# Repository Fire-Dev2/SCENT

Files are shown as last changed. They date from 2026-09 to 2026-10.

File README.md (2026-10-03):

# SCENT

Low-cost embedded electronic nose for volatile organic compound (VOC) headspace classification.

Data, acquisition code, and analysis code supporting:

> Nambi, T., Bhimireddy, N. & McElroy, J. P. *Isolating the contributions of
> resistance-ratio normalization and humidity fusion in a low-cost three-sensor
> offline electronic nose.* Manuscript sensors-4609768, under revision at *Sensors*.

---

## What this is

SCENT is an $83 open-hardware electronic nose. Three MQ-series metal oxide semiconductor (MOS) gas sensors sit in a 3D-printed PETG chamber with active purge fluidics. Acquisition, feature extraction, and classification all run on a Raspberry Pi 5 with no network dependency.

The chamber STL and the Fritzing wiring sketch are in [`hardware/`](hardware/).

Three results. Every figure below is the **mean ± SD across ten random seeds**,
each seed shared by the fold splitter and the forest, with the observed range in
brackets. Earlier versions of this README quoted a single seed's across-fold
spread, which is a different and smaller quantity.

| Feature set | Dataset | Accuracy |
|---|---|---|
| Three MQ channels | primary, n = 450 | **90.2 ± 0.5%** (89.3–90.9), chance 11.1% |
| Three MQ + BME680 relative humidity | primary, n = 450 | **99.3 ± 0.2%** (99.1–99.6) |
| Raw divider voltage | ablation, n = 245 | **86.2 ± 0.9%** (85.3–87.3) |
| Rs/R0 normalized | ablation, n = 245 | **82.4 ± 1.9%** (79.2–84.9) |

Humidity fusion is significant at every seed (McNemar p from 5.4×10⁻¹¹ to
6.8×10⁻⁹). Resistance-ratio normalization is not: across ten seeds McNemar p
ranges from 0.034 to 1.00, and only two of ten fall below 0.05. For the forest the 3.8-point drop
reaches trial-level significance at only two of ten seeds, but the same division
costs two linear classifiers 8-9 points, at eight and ten of ten seeds. The claim
is therefore **no benefit and a consistent cost**, not a neutral transform.

The residual glycerol/water confusion under the three MQ channels is physical, not a signal-conditioning artifact: both headspaces are water-dominated at ambient temperature. Resistance-ratio referencing does not resolve it; a humidity transducer does.

A leave-one-sensor-out ablation (`analysis/loso.py`) shows the array is not
minimal: differencing the full and reduced
models seed by seed, dropping **MQ-9** costs 0.89 ± 0.63 points on three channels,
with the two-channel model the more accurate at one of ten seeds, and −0.13 ± 0.16
points on four, where the reduced model is at least as accurate at every seed.
Dropping MQ-3 costs 8.58 ± 0.69 points and MQ-135 2.62 ± 0.63.

Repeated under the preparation-level holdout (train on batch A, test on the
held-out batch B), the direction is the same and somewhat stronger: dropping
MQ-9 costs −0.89 ± 2.61 points on three channels and −1.22 ± 1.92 on four, with
the reduced model at least as accurate at **8 of 10** seeds in both cases, while
dropping MQ-3 costs 10.89 ± 2.39 and 8.22 ± 2.17. The held-out preparation is 90
trials, so the intervals are wide; this constrains the direction of the MQ-9
result, not its magnitude.

---

## Repository contents

```
SCENT/
├── data/                  # 18 per-analyte CSVs = 450-trial primary acquisition;
│                        # New_Protocol_Dataset.csv = 245-trial ablation acquisition
│                        # (file-by-file breakdown under "Data" below)
├── hardware/              # chamber STL, Fritzing wiring sketch, part list
├── analysis/
│   ├── seed_sweep.py      # ten-seed sweep over the four feature sets
│   ├── loso.py            # leave-one-sensor-out and single-channel ablation
│   ├── learning_curve.py  # held-out accuracy against training-set size
│   └── tvoc_checks.py     # exclusion evidence for the CCS811 channel
├── results/               # JSON output of each script above, plus the per-seed CSV
├── acquisition.py         # runs one trial on the Raspberry Pi
├── scent_analysis.py      # single-seed results and Figures 3–6
├── Requirements.txt
├── LICENSE                # MIT — code
├── LICENSE-DATA           # CC BY 4.0 — data
└── README.md
```

`figures/` is generated output and is not committed.

---

## Acquisition

`acquisition.py` runs one trial of the three-phase protocol on the Pi:

| Phase | Duration | |
|---|---|---|
| baseline | 30 s | clean-air stabilization before the sample is introduced |
| exposure | 60 s | sample headspace present |
| purge | 120 s | active exhaust, sensors returning to baseline |

```bash
python3 acquisition.py --trial 1 --scent ethanol --outdir data
```

All channels are sampled at **1 Hz** and each phase is reduced to the **arithmetic mean** of its samples, so one trial yields one value per channel per phase and the script writes one record per trial.

**The analyses in the manuscript use the exposure-phase columns.** The deposited datasets below carry those columns only, under the shorter names given in the column table.

Two implementation details the manuscript relies on:

- The CCS811 environmental compensation register (`ENV_DATA`, `0x05`) is never written, so the TVOC and eCO2 outputs are independent of the BME680 readings.
- `wait_ccs_ready()` polls the data-ready flag before every read, so logged values are never stale returns from a failed transaction.

Hardware: MQ-3, MQ-9, and MQ-135 read through an ADS1115 on A0/A1/A2; BME680 for temperature and relative humidity; CCS811 for eCO2 and TVOC. All on I²C.

---

## Reproducing the reported values

```bash
git clone https://github.com/Fire-Dev2/SCENT.git
cd SCENT
pip install -r Requirements.txt

python3 scent_analysis.py --data-dir data --out-dir figures   # single-seed results, Figures 3-6
python3 analysis/seed_sweep.py                                 # the reported mean +/- SD
python3 analysis/loso.py                                       # leave-one-sensor-out
python3 analysis/learning_curve.py                             # accuracy vs training-set size
python3 analysis/tvoc_checks.py                                # CCS811 exclusion evidence
```

The four scripts in `analysis/` default to `--data-dir data --out-dir results`
and need no arguments from the repository root.

`scent_analysis.py` takes a few minutes, dominated by the label-permutation
test; pass `--permutations 60` to shorten it. `seed_sweep.py` and `loso.py`
fit ten seeds each and take a few minutes more.

**On seeds.** `scent_analysis.py` is deterministic at `random_state=42`, but a
single seed is a reproducibility guarantee, not an uncertainty estimate. Seed 42
sits at the top of the ten-seed range for humidity fusion and at the bottom for
the normalized ablation, so it flatters one result and penalises the other. The
intervals quoted in this README and in the manuscript come from
`analysis/seed_sweep.py`, which is the number to compare against.

**Outputs written to `figures/`:**

| Output | Corresponds to |
|---|---|
| `Figure2_confusion_matrix.png` / `.pdf` | Manuscript Fig. 3 |
| `Figure3_humidity_fusion.png` / `.pdf` | Manuscript Fig. 6 |
| `FigureS1_feature_importance.png` | Manuscript Fig. 4 |
| `FigureS2_normalization_ablation.png` | Manuscript Fig. 5 |
| `TableI_normalization.csv` | Manuscript Table 3 |
| `TableII_per_class_primary.csv` | Manuscript Table 1 |
| `TableS1_classifiers.csv` | Manuscript Table 2 |
| `TableS2_ablation_per_class.csv` | Per-class ablation detail |
| `TableS3_humidity_fusion.csv` | Manuscript Table 4 |
| `results_summary.json` | Every single-seed statistic, machine-readable |

**Outputs written to `results/` by the scripts in `analysis/`:**

| Output | Corresponds to |
|---|---|
| `seed_sweep_results.json`, `seed_sweep_per_seed.csv` | Manuscript Table 8, the reported intervals |
| `loso_results.json` | Leave-one-sensor-out and its preparation-level repeat, Section 3.3, Tables S5/S5b/S5c |
| `learning_curve_results.json` | Manuscript Fig. 9 |
| `tvoc_checks_results.json` | Supplementary Tables S1–S4 |

The script also prints the exact binomial and permutation tests against chance, the McNemar and paired-t tests on the normalization ablation, the batch and cross-day holdouts, the seven-classifier comparison, and the per-analyte mean humidity that underpins the physical explanation.

**Versions used for the reported numbers:** Python 3.12.3, scikit-learn 1.8.0, statsmodels, scipy, numpy, pandas, matplotlib. Minor scikit-learn version differences may shift accuracy in the third decimal place.

---

## Data

### Primary dataset — 450 trials

In `data/`. Nine analytes, 50 trials each, acquired in two batches per analyte (40 and 10 trials) **on separate days**. Trial order was randomized and interleaved across analytes rather than blocked, so within-session baseline drift is distributed across classes rather than confounded with class identity.

| Analyte | Batch A (40 trials) | Batch B (10 trials) |
|---|---|---|
| Acetone | `MQ-3_Sensor_Data_Acetone_80.csv` | `MQ-3_Sensor_Data_Acetone_20.csv` |
| Acetic acid | `Acetic_Acid_80_Data.csv` | `Acetic_Acid_20_Data.csv` |
| Ammonia | `MQ-3_Sensor_Data_Ammonia_80.csv` | `MQ-3_Sensor_Data_Ammonia_20.csv` |
| Distilled water | `MQ-3_Sensor_Data_Distilled_Water_80.csv` | `MQ-3_Sensor_Data_Distilled_Water_20.csv` |
| Ethanol | `Ethanol_80_Sensor_Data.csv` | `Ethanol_20_Sensor_Data.csv` |
| Ethyl acetate | `Ethyl_Acetate_80_Sensor_Data.csv` | `Ethyl_Acetate_20.csv` |
| Glycerol | `Glycerol_80_Data.csv` | `Glycerol_20_Sensor_Data.csv` |
| Hydrogen peroxide | `Hydrogen_Peroxide_80_Sensor_Data.csv` | `Hydrogen_Peroxide_20.csv` |
| Propylene glycol | `Propylene_Glycol_80_Data.csv` | `Propylene_Glycol_20_Sensor_Data.csv` |

The `_80` / `_20` suffixes refer to the trial split, not to concentration. All analytes were used undiluted as purchased, 5 mL per trial, equilibrated 30 min before sampling.

### Ablation dataset — 245 trials

In `data/New_Protocol_Dataset.csv`. Same nine analytes under a modified protocol in which the **clean-air baseline resistance R₀ of each channel was recorded immediately before every exposure**, permitting resistance-ratio features to be computed per trial. Acquired over two days (`Batch_Day` column): 35 trials each for glycerol and distilled water, the pair responsible for the dominant error mode, and 25 for each of the other seven.

This is a separate acquisition from the primary dataset, so the headline three-channel accuracy and the raw-versus-normalized comparison are **not matched trial-for-trial** — stated as a limitation in the manuscript.

### Column format

| Column | Units | Description |
|---|---|---|
| `MQ3_V` | V | MQ-3 divider output (alcohol-sensitive) |
| `MQ9_V` | V | MQ-9 divider output (combustible aliphatics, CO) |
| `MQ135_V` | V | MQ-135 divider output (air quality, NH₃) |
| `MQ3_R0`, `MQ9_R0`, `MQ135_R0` | load-resistor units | Per-trial clean-air baseline resistance (ablation dataset only) |
| `TVOC_ppb` | ppb | Total VOC, CCS811 — **excluded from all analyses, see below** |
| `eCO2_ppm` | ppm | Equivalent CO₂, CCS811 |
| `Temp_C` | °C | In-chamber temperature, BME680 |
| `Humidity_pct` | % RH | In-chamber relative humidity, BME680 |
| `Trial_ID` | — | Trial index within analyte |
| `Batch_Day` | — | Acquisition day (ablation dataset only) |
| `Label` | — | Analyte name |

Every value is the mean over the 60 s exposure phase, 60 samples per trial.

**Classifier inputs:** the three MQ voltages for the primary result; those three plus `Humidity_pct` for the fusion result; Rs/R0 derived from the MQ voltages and the R₀ columns for the ablation. `eCO2_ppm` and `Temp_C` are evaluated as alternative fourth features but are not part of the headline model.

### The TVOC column

`TVOC_ppb` is **excluded from every analysis** and is retained only for completeness. Across both datasets the nine analyte classes occupy strictly disjoint TVOC bands, with a minimum inter-class gap of +4.635 pooled standard deviations and no overlap in any of the 36 class pairs; every other channel has a negative minimum gap and overlapping pairs. Fitted alone the channel classifies all nine analytes at 100.0 ± 0.0%.

Acquisition-order artifacts, derivation from the MOS channels, environmental compensation, cached reads, and quantization have been excluded. The behavior is unexplained and is reported as such in the manuscript. Do not use this column.

### Feature definitions

Raw features are the divider voltages as logged. Resistance-ratio features are computed as

```
Rs/RL = (Vc / Vout) − 1        with Vc = 5 V
feature = (Rs/RL) / R0         per channel, per trial
```

R₀ is logged in load-resistor units, so RL cancels in the ratio.

### Data integrity

The analysis script runs automatic checks before computing any metric: trial counts, class balance, exact-duplicate detection, and per-analyte signal spread. The spread check exists because a batch of genuinely independent trials varies well above ADC quantisation; a near-zero spread indicates replicated or derived rows rather than independent measurements. Both datasets pass, and the check prints a warning naming any analyte that fails.

---

## Licensing

- **Code**: MIT — see `LICENSE`
- **Data**: CC BY 4.0 — see `LICENSE-DATA`

Both permit reuse with attribution.

---

## Citation

Please cite the manuscript. The repository is referenced in the paper as:

```
https://github.com/Fire-Dev2/SCENT
```

Tagged releases are listed under Releases.

---

## Contact

Tharun Nambi — tharun.nambi@osumc.edu — ORCID [0009-0001-1177-6635](https://orcid.org/0009-0001-1177-6635)

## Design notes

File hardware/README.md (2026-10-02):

# Hardware

Design files for the SCENT chamber and sensor wiring.

| File | What it is |
|---|---|
| `SCENT_chamber.stl` | Sensor chamber, binary STL, 21,512 triangles |
| `SCENT_wiring.fzz` | Fritzing sketch — the full wiring, editable source |
| `SCENT_wiring_breadboard.png` | Breadboard view exported from that sketch |

## Chamber

Printed in PETG. The mesh bounding box is **161.0 × 101.6 × 200.0** model
units; STL stores no unit, and the model was authored in millimetres.

Open `SCENT_chamber.stl` in any slicer. No supports were used for the
reported build.

## Wiring

`SCENT_wiring.fzz` opens in [Fritzing](https://fritzing.org). The Fritzing
library names the ADS1115, BME680 and CCS811 parts after Adafruit because those
are the symbols it ships; the units actually built with were generic
equivalents, as `BOM.csv` records:

| Part | Role |
|---|---|
| Raspberry Pi 5 | acquisition host, I²C master |
| ADS1115 | 16-bit I²C ADC, reads the three MOS dividers on A0/A1/A2 |
| MQ-3 breakout | alcohols |
| MQ-9 breakout | combustible aliphatics, CO |
| Gas sensor breakout (MQ-135) | air quality, NH₃ |
| BME680 breakout | in-chamber temperature and relative humidity |
| CCS811 breakout | eCO2 and TVOC — logged, excluded from every analysis |
| 2-pin fan | active purge exhaust |
| Momentary push button | trial start |

Wire colours in the breadboard view:

| Colour | Carries |
|---|---|
| Red | 5.5 V supply |
| Purple | 3.3 V supply |
| Blue | ground |
| Orange | analogue output from the MOS breakouts to the ADS1115 |
| Green | I²C address lines |
| Grey | I²C serial data |
| Brown | slow control adapter lines |

The MOS breakouts run at 5 V and reach the Pi only through the ADS1115, so
no 5 V line touches a Pi GPIO pin. The BME680 and CCS811 are 3.3 V I²C
devices on the Pi's own bus.

## Bill of materials

`BOM.csv` — thirteen line items totalling **USD 83.00**, which is the figure
quoted in the manuscript.

| Category | USD |
|---|---|
| Compute (Pi 5 1 GB, PSU, microSD) | 53.00 |
| Sensors (3 × MQ, BME680, CCS811) | 15.80 |
| Electronics (ADS1115, fan, button, breadboard and wire) | 5.95 |
| Chamber (PETG, 750 g at $11/kg) | 8.25 |
| **Total** | **83.00** |

Read it with these caveats:

- **Component cost only.** No shipping, tax, soldering iron, printer or
  laptop. The build assumes you already have a 3D printer.
- **Sourcing.** Everything but the Raspberry Pi came from AliExpress. The
  sensor breakouts are generic rather than Adafruit or SparkFun parts, which
  is most of why the sensing array comes to $15.80; the equivalent
  Adafruit units would roughly treble that line.
- **Not calibrated parts.** Generic MOS breakouts carry no calibration
  certificate and unit-to-unit variation is not characterised here. The
  classification results are for the specific units built, which is already
  a stated limitation.
- **Prices move.** The Pi 5 1 GB exists at $45 because memory prices rose;
  the same pressure moves the other lines. The total is the cost at the time of purchase.
- **Filament is the softest line.** 750 g at $0.011/g is the amount of PETG
  attributed to one chamber. If that is a spool purchased rather than the
  mass the slicer reports for this print, the per-device figure is lower and
  the total falls below 83.

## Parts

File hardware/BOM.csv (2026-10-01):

Part | Qty | Supplier | Unit USD | Line USD | Role
Raspberry Pi 5, 1 GB | 1 | PiShop / approved reseller | 45.00 | 45.00 | compute module
Power supply, 5 V 3 A USB-C (generic) | 1 | AliExpress | 4.00 | 4.00
microSD card, 32 GB | 1 | AliExpress | 4.00 | 4.00
ADS1115 16-bit I2C ADC | 1 | AliExpress | 2.00 | 2.00 | reads the three MOS dividers
MQ-3 breakout | 1 | AliExpress | 1.30 | 1.30 | alcohols
MQ-9 breakout | 1 | AliExpress | 1.50 | 1.50 | combustible aliphatics, CO
MQ-135 breakout | 1 | AliExpress | 1.50 | 1.50 | air quality, NH3
BME680 breakout (generic) | 1 | AliExpress | 6.50 | 6.50 | temperature, relative humidity
CCS811 breakout (generic) | 1 | AliExpress | 5.00 | 5.00 | eCO2, TVOC; logged, excluded from analysis
Fan, 2-pin | 1 | AliExpress | 1.20 | 1.20 | active purge exhaust
Momentary push button | 1 | AliExpress | 0.25 | 0.25 | trial start
Breadboard and jumper wires | 1 | AliExpress | 2.50 | 2.50
PETG filament, 750 g | 1 | AliExpress, $11/kg | 8.25 | 8.25 | chamber print; $0.011/g
TOTAL |  |  |  | 83.00

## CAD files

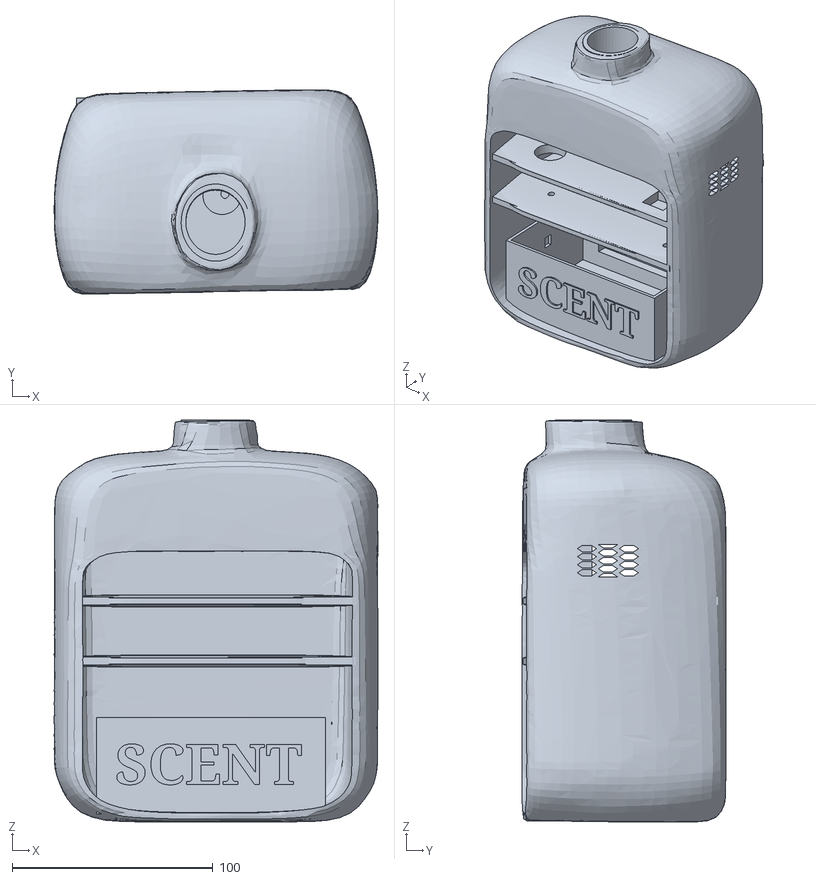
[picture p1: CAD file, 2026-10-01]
hardware/SCENT_chamber.stl
161.0 x 101.6 x 200.0

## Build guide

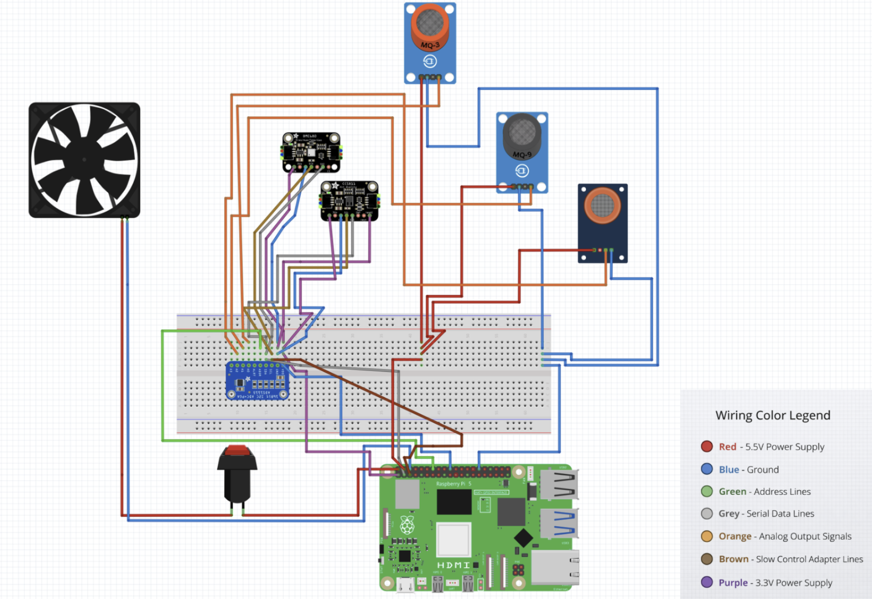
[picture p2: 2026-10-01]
hardware/SCENT_wiring_breadboard.png

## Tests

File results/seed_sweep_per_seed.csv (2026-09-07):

seed | feature_set | accuracy_pct | mcnemar_p_humidity_fusion_B_vs_A | mcnemar_p_normalization_D_vs_C
0 | A. Primary 3-MOS (n=450) | 90.6667
0 | B. Primary 3-MOS + humidity (n=450) | 99.1111 | 1.94671e-09
0 | C. Ablation raw voltage (n=245) | 87.3469
0 | D. Ablation Rs/R0 (n=245) | 84.4898 |  | 0.360196
1 | A. Primary 3-MOS (n=450) | 89.3333
1 | B. Primary 3-MOS + humidity (n=450) | 99.3333 | 5.41216e-11
1 | C. Ablation raw voltage (n=245) | 86.9388
1 | D. Ablation Rs/R0 (n=245) | 83.2653 |  | 0.243243
2 | A. Primary 3-MOS (n=450) | 90.4444
2 | B. Primary 3-MOS + humidity (n=450) | 99.5556 | 1.06106e-09
2 | C. Ablation raw voltage (n=245) | 85.3061
2 | D. Ablation Rs/R0 (n=245) | 81.6327 |  | 0.243243
3 | A. Primary 3-MOS (n=450) | 90.2222
3 | B. Primary 3-MOS + humidity (n=450) | 99.5556 | 2.50886e-10
3 | C. Ablation raw voltage (n=245) | 85.3061
3 | D. Ablation Rs/R0 (n=245) | 84.8980 |  | 1
4 | A. Primary 3-MOS (n=450) | 90.2222
4 | B. Primary 3-MOS + humidity (n=450) | 99.3333 | 4.18544e-10
4 | C. Ablation raw voltage (n=245) | 87.3469
4 | D. Ablation Rs/R0 (n=245) | 81.6327 |  | 0.0714235
5 | A. Primary 3-MOS (n=450) | 89.5556
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

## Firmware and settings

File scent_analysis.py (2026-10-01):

#!/usr/bin/env python3
"""
SCENT: nine-class chemical headspace classification from a low-cost MOS sensor array.

Reproduces the single-seed results and Figures 2-5.

The seed sweep, leave-one-sensor-out ablation, learning curve and CCS811
exclusion checks live in analysis/ and are run separately. The intervals
quoted in the manuscript come from analysis/seed_sweep.py, not from the
across-fold spread this script prints.

  Primary dataset (450 trials, 9 analytes, 3 MQ channels)
    five-fold stratified CV accuracy and macro F1; exact binomial and
    label-permutation tests against chance; per-class precision/recall (Table II);
    pooled out-of-fold confusion matrix (Fig. 2); Gini channel importances (Fig. S1);
    batch holdout across acquisition days; seven-classifier comparison (Table S1).

  Ablation dataset (245 trials, per-trial clean-air R0 recorded)
    raw divider voltage vs Rs/R0 features (Table I); McNemar and paired t tests;
    per-class F1 under both representations (Table S2); confusion matrices (Fig. S2).

  Humidity fusion (both datasets)
    BME680 relative humidity as a fourth feature (Fig. 3, Table S3);
    McNemar against the three-channel model.

Usage:
    python scent_analysis.py --data-dir data --out-dir figures
    python scent_analysis.py --data-dir data --out-dir figures --permutations 200

Deterministic at random_state=42, which is a reproducibility guarantee and
not an uncertainty estimate; see analysis/seed_sweep.py. Runtime is a few minutes, dominated by the
permutation test; lower --permutations to shorten it.
"""

import argparse, json, sys
from pathlib import Path

import numpy as np
import pandas as pd
from sklearn.ensemble import RandomForestClassifier
from sklearn.linear_model import LogisticRegression
from sklearn.metrics import accuracy_score, classification_report, confusion_matrix
from sklearn.model_selection import (StratifiedKFold, cross_val_predict,
                                     cross_val_score, permutation_test_score)
from sklearn.naive_bayes import GaussianNB
from sklearn.neighbors import KNeighborsClassifier
from sklearn.pipeline import make_pipeline
from sklearn.preprocessing import StandardScaler
from sklearn.svm import SVC
from sklearn.tree import DecisionTreeClassifier

RANDOM_STATE = 42
N_ESTIMATORS = 100
N_SPLITS = 5
VC = 5.0

MQ = ["MQ3_V", "MQ9_V", "MQ135_V"]
R0 = ["MQ3_R0", "MQ9_R0", "MQ135_R0"]
RH = "Humidity_pct"

PRIMARY = {
    "Acetone":           ("MQ-3_Sensor_Data_Acetone_80.csv", "MQ-3_Sensor_Data_Acetone_20.csv"),
    "Acetic_Acid":       ("Acetic_Acid_80_Data.csv", "Acetic_Acid_20_Data.csv"),
    "Ammonia":           ("MQ-3_Sensor_Data_Ammonia_80.csv", "MQ-3_Sensor_Data_Ammonia_20.csv"),
    "Distilled_Water":   ("MQ-3_Sensor_Data_Distilled_Water_80.csv", "MQ-3_Sensor_Data_Distilled_Water_20.csv"),
    "Ethanol":           ("Ethanol_80_Sensor_Data.csv", "Ethanol_20_Sensor_Data.csv"),
    "Ethyl_Acetate":     ("Ethyl_Acetate_80_Sensor_Data.csv", "Ethyl_Acetate_20.csv"),
    "Glycerol":          ("Glycerol_80_Data.csv", "Glycerol_20_Sensor_Data.csv"),
    "Hydrogen_Peroxide": ("Hydrogen_Peroxide_80_Sensor_Data.csv", "Hydrogen_Peroxide_20.csv"),
    "Propylene_Glycol":  ("Propylene_Glycol_80_Data.csv", "Propylene_Glycol_20_Sensor_Data.csv"),
}
ABLATION = "New_Protocol_Dataset.csv"

DISPLAY = {"Acetic_Acid":"Acetic acid","Acetone":"Acetone","Ammonia":"Ammonia",
 "Distilled_Water":"Distilled water","Ethanol":"Ethanol","Ethyl_Acetate":"Ethyl acetate",
 "Glycerol":"Glycerol","Hydrogen_Peroxide":"Hydrogen peroxide","Propylene_Glycol":"Propylene glycol"}
CHANNEL = {"MQ3_V":"MQ-3 (alcohol)","MQ9_V":"MQ-9 (combustible aliphatics, CO)",
 "MQ135_V":"MQ-135 (air quality / NH3)", RH:"BME680 (relative humidity)"}


def rf():
    return RandomForestClassifier(n_estimators=N_ESTIMATORS, random_state=RANDOM_STATE)

def folds():
    return StratifiedKFold(n_splits=N_SPLITS, shuffle=True, random_state=RANDOM_STATE)


def load_primary(data_dir):
    frames, missing = [], []
    for analyte, (fa, fb) in PRIMARY.items():
        for fname, batch in ((fa, "A"), (fb, "B")):
            p = data_dir / fname
            if not p.exists():
                missing.append(fname); continue
            d = pd.read_csv(p); d["Analyte"] = analyte; d["Batch"] = batch
            frames.append(d)
    if missing:
        sys.exit(f"Missing {len(missing)} primary file(s) in {data_dir}:\n  " + "\n  ".join(missing))
    return pd.concat(frames, ignore_index=True)


def load_ablation(data_dir):
    p = data_dir / ABLATION
    if not p.exists():
        sys.exit(f"Missing ablation dataset: {p}")
    d = pd.read_csv(p)
    d["Analyte"] = d["Label"].str.replace(" ", "_")
    return d


def rs_over_r0(df):
    """Rs/RL = (Vc/Vout - 1), divided by the per-trial R0 of the same channel.
    R0 is logged in load-resistor units, so RL cancels."""
    rs = np.column_stack([(VC / df[c].values - 1) for c in MQ])
    return rs / df[R0].values


def integrity(df, name, feats):
    counts = df["Analyte"].value_counts()
    n_dup = int(df.duplicated(subset=feats).sum())
    print(f"=== {name}: integrity ===")
    print(f"  trials {len(df)}, classes {counts.size}, per class {counts.min()}-{counts.max()}")
    print(f"  exact duplicate feature rows: {n_dup}")
    flagged = []
    for a in sorted(df["Analyte"].unique()):
        s = df[df["Analyte"] == a]
        spread = float(s["MQ3_V"].max() - s["MQ3_V"].min())
        if spread < 0.005:
            flagged.append((a, spread))
    if flagged:
        print("  LOW-VARIANCE WARNING (possible derived or replicated rows):")
        for a, s in flagged:
            print(f"    {a}: MQ3_V spread {s:.5f} V")
    else:
        print("  per-analyte MQ3_V spread: all above quantisation floor")
    print()
    return {"n": int(len(df)), "duplicates": n_dup,
            "low_variance_analytes": [a for a, _ in flagged]}


def analyse_primary(df, n_perm):
    from scipy.stats import binomtest
    X, y = df[MQ].values, df["Analyte"].values
    classes = sorted(set(y)); chance = 1.0 / len(classes); cv = folds()

    acc = cross_val_score(rf(), X, y, cv=cv, scoring="accuracy")
    f1  = cross_val_score(rf(), X, y, cv=cv, scoring="f1_macro")
    yp  = cross_val_predict(rf(), X, y, cv=cv)
    ncorr = int((yp == y).sum())

    print("=== Primary dataset, three MQ channels ===")
    print(f"  accuracy {acc.mean()*100:.1f} +/- {acc.std()*100:.1f}%   macro F1 {f1.mean():.3f} +/- {f1.std():.3f}")
    print(f"  folds {np.round(acc,4)}")
    print(f"  {ncorr}/{len(y)} correct; chance {chance*100:.1f}%")
    bp = binomtest(ncorr, len(y), chance, alternative="greater").pvalue
    print(f"  exact binomial p = {bp:.3e}")

    score, perm, pp = permutation_test_score(rf(), X, y, scoring="accuracy", cv=cv,
        n_permutations=n_perm, random_state=RANDOM_STATE, n_jobs=-1)
    print(f"  permutation ({n_perm}): permuted {perm.mean()*100:.1f} +/- {perm.std()*100:.1f}%, "
          f"max {perm.max()*100:.1f}%, p = {pp:.4f}")
    print(f"    (minimum attainable p = {1/(n_perm+1):.4f})")

    a, b = df[df.Batch=="A"], df[df.Batch=="B"]
    ho = accuracy_score(b["Analyte"], rf().fit(a[MQ], a["Analyte"]).predict(b[MQ]))
    print(f"  batch holdout (train day 1 -> test day 2): {ho*100:.1f}%")

    imp = dict(zip(MQ, rf().fit(X, y).feature_importances_.tolist()))
    print("  Gini importances: " + ", ".join(f"{k} {v:.3f}" for k, v in imp.items()))
    print(); print(classification_report(y, yp, digits=3))

    rep = classification_report(y, yp, output_dict=True, digits=3)
    return {"classes":classes,"chance":chance,
            "accuracy_mean":float(acc.mean()),"accuracy_std":float(acc.std()),
            "macro_f1_mean":float(f1.mean()),"macro_f1_std":float(f1.std()),
            "n_correct":ncorr,"n_total":int(len(y)),"binomial_p":float(bp),
            "permutation_p":float(pp),"permuted_mean":float(perm.mean()),
            "permuted_std":float(perm.std()),"permuted_max":float(perm.max()),
            "batch_holdout":float(ho),"importances":imp,
            "per_class":{c:rep[c] for c in classes},
            "confusion_matrix":confusion_matrix(y,yp,labels=classes).tolist()}


def compare_classifiers(df):
    X, y = df[MQ].values, df["Analyte"].values
    cv = folds()
    models = {
      "Support vector machine (RBF)": make_pipeline(StandardScaler(), SVC(kernel="rbf", random_state=RANDOM_STATE)),
      "Support vector machine (linear)": make_pipeline(StandardScaler(), SVC(kernel="linear", random_state=RANDOM_STATE)),
      "Gaussian naive Bayes": make_pipeline(StandardScaler(), GaussianNB()),
      "Logistic regression": make_pipeline(StandardScaler(), LogisticRegression(max_iter=5000)),
      "k-nearest neighbors (k = 5)": make_pipeline(StandardScaler(), KNeighborsClassifier(n_neighbors=5)),
      "Decision tree": DecisionTreeClassifier(random_state=RANDOM_STATE),
      "Random forest (100 trees, deployed)": rf(),
    }
    print("=== Classifier comparison, identical folds (Table S1) ===")
    out = {}
    for name, m in models.items():
        a = cross_val_score(m, X, y, cv=cv, scoring="accuracy")
        f = cross_val_score(m, X, y, cv=cv, scoring="f1_macro")
        out[name] = {"accuracy_mean":float(a.mean()),"accuracy_std":float(a.std()),
                     "macro_f1":float(f.mean())}
        print(f"  {name:36s} {a.mean()*100:5.1f} +/- {a.std()*100:4.1f}%   F1 {f.mean():.3f}")
    print()
    return out


def analyse_ablation(df):
    from scipy.stats import ttest_rel
    from statsmodels.stats.contingency_tables import mcnemar
    y = df["Analyte"].values; classes = sorted(set(y)); cv = folds()
    sets = {"raw": df[MQ].values, "norm": rs_over_r0(df)}
    res, preds = {}, {}
    print("=== Normalization ablation ===")
    for k, X in sets.items():
        a = cross_val_score(rf(), X, y, cv=cv, scoring="accuracy")
        f = cross_val_score(rf(), X, y, cv=cv, scoring="f1_macro")
        p = cross_val_predict(rf(), X, y, cv=cv); preds[k] = p
        rep = classification_report(y, p, output_dict=True, digits=3)
        others = [c for c in classes if c not in ("Glycerol","Distilled_Water")]
        res[k] = {"accuracy_mean":float(a.mean()),"accuracy_std":float(a.std()),
                  "macro_f1":float(f.mean()),"fold_accuracies":a.tolist(),
                  "glycerol_f1":rep["Glycerol"]["f1-score"],
                  "water_f1":rep["Distilled_Water"]["f1-score"],
                  "other_seven_mean_recall":float(np.mean([rep[c]["recall"] for c in others])),
                  "per_class_f1":{c:rep[c]["f1-score"] for c in classes},
                  "support":{c:int(rep[c]["support"]) for c in classes},
                  "confusion_matrix":confusion_matrix(y,p,labels=classes).tolist()}
        r = res[k]
        print(f"  {k:5s} accuracy {r['accuracy_mean']*100:5.1f} +/- {r['accuracy_std']*100:4.1f}%   "
              f"glycerol F1 {r['glycerol_f1']:.3f}   water F1 {r['water_f1']:.3f}   "
              f"other seven recall {r['other_seven_mean_recall']:.3f}")

    ok_r, ok_n = (preds["raw"]==y), (preds["norm"]==y)
    b = int((ok_r & ~ok_n).sum()); c = int((~ok_r & ok_n).sum())
    tbl = [[int((ok_r & ok_n).sum()), b],[c, int((~ok_r & ~ok_n).sum())]]
    mp = float(mcnemar(tbl, exact=True).pvalue)
    t, tp = ttest_rel(res["raw"]["fold_accuracies"], res["norm"]["fold_accuracies"])
    print(f"  paired: both correct {tbl[0][0]}, raw only {b}, norm only {c}, both wrong {tbl[1][1]}")
    print(f"  McNemar exact p = {mp:.4f};  paired t across folds p = {tp:.4f}")
    if mp >= 0.05:
        print("  -> not significant; claim no benefit, not active degradation")

    d1, d2 = df[df.Batch_Day==1], df[df.Batch_Day==2]
    cross = {"raw": float(accuracy_score(d2["Analyte"],
                rf().fit(d1[MQ], d1["Analyte"]).predict(d2[MQ]))),
             "norm": float(accuracy_score(d2["Analyte"],
                rf().fit(rs_over_r0(d1), d1["Analyte"]).predict(rs_over_r0(d2))))}
    print(f"  cross-day holdout: raw {cross['raw']*100:.1f}%, normalized {cross['norm']*100:.1f}%")
    print()
    res.update({"mcnemar_table":tbl,"mcnemar_p":mp,"paired_t_p":float(tp),
                "cross_day":cross,"classes":classes})
    return res


def analyse_fusion(primary, ablation):
    from statsmodels.stats.contingency_tables import mcnemar
    cv = folds(); out = {}
    print("=== Humidity fusion ===")
    for name, df in (("primary", primary), ("ablation", ablation)):
        y = df["Analyte"].values; classes = sorted(set(y))
        X3, X4 = df[MQ].values, df[MQ+[RH]].values
        a3 = cross_val_score(rf(), X3, y, cv=cv, scoring="accuracy")
        a4 = cross_val_score(rf(), X4, y, cv=cv, scoring="accuracy")
        f4 = cross_val_score(rf(), X4, y, cv=cv, scoring="f1_macro")
        p3 = cross_val_predict(rf(), X3, y, cv=cv)
        p4 = cross_val_predict(rf(), X4, y, cv=cv)
        rep = classification_report(y, p4, output_dict=True, digits=3)
        ok3, ok4 = (p3==y), (p4==y)
        b = int((ok3 & ~ok4).sum()); c = int((~ok3 & ok4).sum())
        mp = float(mcnemar([[int((ok3&ok4).sum()), b],[c, int((~ok3&~ok4).sum())]],
                           exact=True).pvalue)
        e = {"three_channel_accuracy":float(a3.mean()),
             "four_channel_accuracy":float(a4.mean()),
             "four_channel_accuracy_std":float(a4.std()),
             "four_channel_macro_f1":float(f4.mean()),
             "n_correct_four":int(ok4.sum()),"n_total":int(len(y)),
             "glycerol_f1":rep["Glycerol"]["f1-score"],
             "water_f1":rep["Distilled_Water"]["f1-score"],
             "mcnemar_p":mp,"classes":classes,
             "per_class":{cl:rep[cl] for cl in classes},
             "confusion_matrix_four":confusion_matrix(y,p4,labels=classes).tolist()}
        if name == "primary":
            e["importances_four"] = dict(zip(MQ+[RH],
                rf().fit(X4, y).feature_importances_.tolist()))
            a, bb = df[df.Batch=="A"], df[df.Batch=="B"]
            e["batch_holdout_four"] = float(accuracy_score(bb["Analyte"],
                rf().fit(a[MQ+[RH]], a["Analyte"]).predict(bb[MQ+[RH]])))
        out[name] = e
        print(f"  {name:9s} 3-channel {a3.mean()*100:5.1f}% -> 4-channel "
              f"{a4.mean()*100:5.1f} +/- {a4.std()*100:.1f}%   "
              f"glycerol F1 {e['glycerol_f1']:.3f}   water F1 {e['water_f1']:.3f}   "
              f"McNemar p = {mp:.2e}")
    if "importances_four" in out["primary"]:
        print("  four-feature importances: " + ", ".join(
            f"{k} {v:.3f}" for k, v in out["primary"]["importances_four"].items()))
        print(f"  batch holdout with humidity: {out['primary']['batch_holdout_four']*100:.1f}%")
    print("\n  mean relative humidity by analyte (primary):")
    for a in sorted(primary["Analyte"].unique()):
        print(f"    {DISPLAY[a]:20s} {primary[primary.Analyte==a][RH].mean():.1f}%")
    print()
    return out


def _cm(ax, cm, labels, title, show_y=True, vmax=50):
    im = ax.imshow(cm, cmap="Blues", vmin=0, vmax=vmax)
    ax.set_xticks(range(len(labels))); ax.set_yticks(range(len(labels)))
    ax.set_xticklabels(labels, rotation=45, ha="right", fontsize=7)
    ax.set_yticklabels(labels if show_y else [""]*len(labels), fontsize=7)
    ax.set_xlabel("Predicted class", fontsize=8)
    if show_y: ax.set_ylabel("True class", fontsize=8)
    ax.set_title(title, fontsize=9, loc="left", fontweight="bold")
    for i in range(cm.shape[0]):
        for j in range(cm.shape[1]):
            if cm[i,j] > 0:
                ax.text(j,i,str(cm[i,j]),ha="center",va="center",fontsize=6,
                        color="white" if cm[i,j] > vmax/2 else "black")
    return im


def make_figures(pr, ab, fu, out_dir):
    import matplotlib; matplotlib.use("Agg")
    import matplotlib.pyplot as plt
    matplotlib.rcParams["font.family"] = "DejaVu Sans"
    labels = [DISPLAY[c] for c in pr["classes"]]

    fig, ax = plt.subplots(figsize=(6.5,5.5))
    im = _cm(ax, np.array(pr["confusion_matrix"]), labels,
             f"Confusion matrix (pooled 5-fold stratified CV, n = {pr['n_total']})")
    fig.colorbar(im, ax=ax, fraction=0.046, pad=0.04).set_label("Trial count")
    fig.tight_layout()
    fig.savefig(out_dir/"Figure2_confusion_matrix.png", dpi=300)
    fig.savefig(out_dir/"Figure2_confusion_matrix.pdf"); plt.close(fig)

    fig, axes = plt.subplots(1,2, figsize=(11,4.8))
    _cm(axes[0], np.array(pr["confusion_matrix"]), labels, "a  Three MOS channels", True)
    im = _cm(axes[1], np.array(fu["primary"]["confusion_matrix_four"]), labels,
             "b  + BME680 humidity", False)
    fig.colorbar(im, ax=axes, fraction=0.024, pad=0.02).set_label("Trial count")
    fig.savefig(out_dir/"Figure3_humidity_fusion.png", dpi=300,
                bbox_inches="tight", facecolor="white")
    fig.savefig(out_dir/"Figure3_humidity_fusion.pdf",
                bbox_inches="tight", facecolor="white"); plt.close(fig)

    imp = pr["importances"]; order = sorted(imp, key=imp.get, reverse=True)
    vals = [imp[k] for k in order]
    fig, ax = plt.subplots(figsize=(5,3.5))
    bars = ax.bar([CHANNEL[k] for k in order], vals, color="#4C72B0")
    ax.set_ylabel("Gini importance")
    ax.set_title(f"Sensor channel importance (random forest, n = {pr['n_total']})")
    ax.set_ylim(0, max(vals)*1.2)
    for bar, v in zip(bars, vals):
        ax.text(bar.get_x()+bar.get_width()/2, v+0.01, f"{v:.3f}", ha="center", fontsize=9)
    plt.xticks(rotation=15, ha="right"); fig.tight_layout()
    fig.savefig(out_dir/"FigureS1_feature_importance.png", dpi=300); plt.close(fig)

    al = [DISPLAY[c] for c in ab["classes"]]
    fig, axes = plt.subplots(1,2, figsize=(11.5,4.8))
    _cm(axes[0], np.array(ab["raw"]["confusion_matrix"]), al,
        "a  Raw divider voltage", True, 35)
    im = _cm(axes[1], np.array(ab["norm"]["confusion_matrix"]), al,
             "b  Rs/R0 normalized", False, 35)
    fig.colorbar(im, ax=axes, fraction=0.024, pad=0.02).set_label("Trial count")
    fig.savefig(out_dir/"FigureS2_normalization_ablation.png", dpi=300,
                bbox_inches="tight", facecolor="white"); plt.close(fig)
    print(f"Figures written to {out_dir}")


def write_tables(pr, ab, fu, cls, out_dir):
    classes = pr["classes"]
    pd.DataFrame([{"Analyte":DISPLAY[c],
                   "Support (n)":int(pr["per_class"][c]["support"]),
                   "Precision":round(pr["per_class"][c]["precision"],3),
                   "Recall":round(pr["per_class"][c]["recall"],3)}
                  for c in classes]).to_csv(out_dir/"TableII_per_class_primary.csv", index=False)

    pd.DataFrame([{"Features":"Raw divider voltage" if k=="raw" else "Rs/R0 normalized",
                   "Accuracy (%)":f"{ab[k]['accuracy_mean']*100:.1f} +/- {ab[k]['accuracy_std']*100:.1f}",
                   "Macro F1":round(ab[k]["macro_f1"],3),
                   "Glycerol F1":round(ab[k]["glycerol_f1"],3),
                   "Water F1":round(ab[k]["water_f1"],3),
                   "Other seven mean recall":round(ab[k]["other_seven_mean_recall"],3)}
                  for k in ("raw","norm")]).to_csv(out_dir/"TableI_normalization.csv", index=False)

    pd.DataFrame([{"Classifier":k,
                   "Accuracy (%)":f"{v['accuracy_mean']*100:.1f} +/- {v['accuracy_std']*100:.1f}",
                   "Macro F1":round(v["macro_f1"],3)}
                  for k,v in cls.items()]).to_csv(out_dir/"TableS1_classifiers.csv", index=False)

    pd.DataFrame([{"Analyte":DISPLAY[c], "n":ab["raw"]["support"][c],
                   "Raw F1":round(ab["raw"]["per_class_f1"][c],3),
                   "Rs/R0 F1":round(ab["norm"]["per_class_f1"][c],3)}
                  for c in ab["classes"]]).to_csv(out_dir/"TableS2_ablation_per_class.csv", index=False)

    fp = fu["primary"]["per_class"]
    pd.DataFrame([{"Analyte":DISPLAY[c], "n":int(fp[c]["support"]),
                   "Precision":round(fp[c]["precision"],3),
                   "Recall":round(fp[c]["recall"],3)}
                  for c in classes]).to_csv(out_dir/"TableS3_humidity_fusion.csv", index=False)
    print(f"Tables written to {out_dir}")


def main():
    ap = argparse.ArgumentParser(description=__doc__,
        formatter_class=argparse.RawDescriptionHelpFormatter)
    ap.add_argument("--data-dir", type=Path, default=Path("../data"))
    ap.add_argument("--out-dir", type=Path, default=Path("../figures"))
    ap.add_argument("--permutations", type=int, default=200)
    args = ap.parse_args()
    args.out_dir.mkdir(parents=True, exist_ok=True)

    primary = load_primary(args.data_dir)
    ablation = load_ablation(args.data_dir)
    integ = {"primary": integrity(primary, "Primary dataset", MQ),
             "ablation": integrity(ablation, "Ablation dataset", MQ)}
    pr  = analyse_primary(primary, args.permutations)
    cls = compare_classifiers(primary)
    ab  = analyse_ablation(ablation)
    fu  = analyse_fusion(primary, ablation)
    make_figures(pr, ab, fu, args.out_dir)
    write_tables(pr, ab, fu, cls, args.out_dir)
    with open(args.out_dir/"results_summary.json","w") as fh:
        json.dump({"integrity":integ,"primary":pr,"classifier_comparison":cls,
                   "ablation":ab,"humidity_fusion":fu}, fh, indent=2)
    print(f"Results JSON written to {args.out_dir/'results_summary.json'}")


if __name__ == "__main__":
    main()

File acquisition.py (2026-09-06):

#!/usr/bin/env python3
"""
SCENT acquisition.

Runs one trial of the three-phase protocol and writes a single record.

    baseline   30 s   clean-air stabilization before the sample is introduced
    exposure   60 s   sample headspace present
    purge     120 s   active exhaust, sensors returning to baseline

All channels are sampled at 1 Hz. Each phase is reduced to the arithmetic
mean of its samples, so one trial yields one value per channel per phase.
The analyses reported in the accompanying manuscript use the exposure-phase
columns.

Hardware
    MQ-3, MQ-9, MQ-135   analog, via ADS1115 on A0/A1/A2
    BME680               temperature, relative humidity
    CCS811               eCO2, TVOC

Note on the CCS811: the environmental compensation register (ENV_DATA, 0x05)
is deliberately never written, so the TVOC and eCO2 outputs are independent of
the BME680 readings.

Usage
    python3 acquisition.py --trial 1 --scent ethanol --outdir data
"""

import argparse
import csv
import time
from datetime import datetime, timezone
from pathlib import Path
from statistics import mean

import board
import busio
import adafruit_ccs811
import adafruit_bme680
import adafruit_ads1x15.ads1115 as ADS
from adafruit_ads1x15.analog_in import AnalogIn

BASELINE_S = 30
EXPOSURE_S = 60
PURGE_S = 120
SAMPLE_HZ = 1.0

CHANNELS = ["tvoc", "eco2", "temp_c", "humidity_pct", "mq3_v", "mq9_v", "mq135_v"]
PHASES = ["baseline", "exposure", "purge"]


def parse_args():
    p = argparse.ArgumentParser(description="Run one SCENT trial.")
    p.add_argument("--trial", required=True, help="trial identifier")
    p.add_argument("--scent", required=True, help="analyte label")
    p.add_argument("--outdir", default="data")
    return p.parse_args()


def wait_ccs_ready(ccs):
    """Block until the CCS811 has a new sample, so reads are never stale."""
    while not ccs.data_ready:
        time.sleep(0.05)


def read_all(ccs, bme, mq3, mq9, mq135):
    wait_ccs_ready(ccs)
    return {
        "tvoc": ccs.tvoc,
        "eco2": ccs.eco2,
        "temp_c": bme.temperature,
        "humidity_pct": bme.relative_humidity,
        "mq3_v": mq3.voltage,
        "mq9_v": mq9.voltage,
        "mq135_v": mq135.voltage,
    }


def collect_phase(sensors, duration):
    """Sample every channel at SAMPLE_HZ for `duration` seconds."""
    samples = []
    interval = 1.0 / SAMPLE_HZ
    end = time.monotonic() + duration
    next_t = time.monotonic()
    while time.monotonic() < end:
        if time.monotonic() >= next_t:
            samples.append(read_all(*sensors))
            next_t += interval
        time.sleep(0.01)
    return samples


def reduce_samples(samples):
    """Arithmetic mean per channel. Missing readings are skipped."""
    if not samples:
        return {k: None for k in CHANNELS}
    out = {}
    for k in CHANNELS:
        vals = [s[k] for s in samples if s.get(k) is not None]
        out[k] = mean(vals) if vals else None
    return out


def main():
    args = parse_args()
    outdir = Path(args.outdir)
    outdir.mkdir(parents=True, exist_ok=True)
    fname = outdir / f"trial_{args.trial}_{args.scent}.csv"

    i2c = busio.I2C(board.SCL, board.SDA)
    ccs = adafruit_ccs811.CCS811(i2c)
    bme = adafruit_bme680.Adafruit_BME680_I2C(i2c)
    ads = ADS.ADS1115(i2c)
    ads.gain = 1
    sensors = (ccs, bme,
               AnalogIn(ads, ADS.P0),   # MQ-3
               AnalogIn(ads, ADS.P1),   # MQ-9
               AnalogIn(ads, ADS.P2))   # MQ-135

    wait_ccs_ready(ccs)

    reduced = {
        "baseline": reduce_samples(collect_phase(sensors, BASELINE_S)),
        "exposure": reduce_samples(collect_phase(sensors, EXPOSURE_S)),
        "purge":    reduce_samples(collect_phase(sensors, PURGE_S)),
    }

    header = ["trial", "scent", "utc"]
    header += [f"{phase}_{ch}" for ch in CHANNELS for phase in PHASES]

    row = [args.trial, args.scent,
           datetime.now(timezone.utc).isoformat(timespec="seconds")]
    row += [reduced[phase][ch] for ch in CHANNELS for phase in PHASES]

    with open(fname, "w", newline="") as f:
        writer = csv.writer(f)
        writer.writerow(header)
        writer.writerow(row)

    print(f"Wrote {fname}")


if __name__ == "__main__":
    main()

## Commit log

2026-09-02 Test 1 Data
    [Averaged Researcher Trials (1).csv, MQ135_S8_Control_Raw.csv, MQ3_S2_Control_Raw.csv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]
2026-09-02 Test 2 Data
    [Acetic Acid 20 Data.csv, Acetic Acid 80 Data.csv, Ethanol 20 Sensor Data.csv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]
2026-09-02 Tests data
    [12 hour fast (baseline).csv, Acetic Acid 20 Data.csv, Acetic Acid 80 Data.csv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]
2026-10-01 Rename deposited CSVs to the names the analysis script expects
    The 19 data files were deposited with spaces in their names ("MQ-3 Sensor
    Data Acetone 80.csv") but scent_analysis.py looks for the underscore form
    ("MQ-3_Sensor_Data_Acetone_80.csv"), which is also the form documented in
    the README column table. Anyone following the reproduction instructions got
    "missing" for all 18 primary files and a hard failure on the ablation file.
    Also flattens the two dataset directories into a single data/, which is what
    --data-dir takes, so the two cp steps in the README are no longer needed.
    No data values changed; these are pure renames.
    Claude-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
    [Acetic_Acid_20_Data.csv, Acetic_Acid_80_Data.csv, Ethanol_20_Sensor_Data.csv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]
2026-10-01 Fix filenames carrying stray leading and trailing spaces
    Three files were committed with whitespace in their names: " License" (leading
    space), "Data License " and "Scent analysis " (trailing). The README refers to
    all three without the stray space, so `python3 "Scent analysis"` as documented
    did not resolve, and the two licence files were awkward to open or link to.
    " License" -> LICENSE
    "Data License " -> LICENSE-DATA
    "Scent analysis " -> scent_analysis.py (+x, .py extension)
    "Seed Sweep per Seed.csv"-> results/seed_sweep_per_seed.csv
    Claude-Session: https://claude.ai/code/session_01KUMHYaBfM6Me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
    [seed_sweep_per_seed.csv]
2026-10-01 Add the four analysis scripts behind the reported statistics
    scent_analysis.py covers the single-seed results and Figures 2-5 only. The
    seed sweep, the TVOC exclusion checks, the learning curve and the
    leave-one-sensor-out ablation were run separately and were never deposited,
    so several reported numbers had no code behind them in the repository.
    analysis/seed_sweep.py ten-seed sweep over the four feature sets,
    with paired McNemar from cross_val_predict
    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
2026-10-01 Deposit the chamber STL and the Fritzing wiring sketch
    The Data Availability Statement offered the hardware design files "from the
    corresponding author on request", which is weaker than the paper's open-
    hardware claim deserves and than reviewers expect. They are deposited here
    instead.
    hardware/SCENT_chamber.stl binary STL, 21,512 triangles,
    bounding box 161.0 x 101.6 x 200.0
    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
    [SCENT_chamber.stl, SCENT_wiring.fzz]
2026-10-01 Correct the README numbers, paths and claims
    Numbers. The headline table quoted one seed's across-fold spread as if it were
    an uncertainty on the result. Replaced with the ten-seed mean +/- SD and range
    from analysis/seed_sweep.py:
    three MQ channels 89.8 +/- 0.8 -> 90.2 +/- 0.5 (89.3-90.9)
    + humidity 99.6 +/- 0.5 -> 99.3 +/- 0.2 (99.1-99.6)
    ablation raw voltage - -> 86.2 +/- 0.9 (85.3-87.3)
    ablation Rs/R0 80.0 +/- 1.5 -> 82.4 +/- 1.9 (79.2-84.9)
    Seed 42 sits at the top of the ten-seed range for humidity fusion and at the
    bottom for the normalized ablation, so the old table both flattered one result
    and overstated the normali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
    [scent_analysis.py]
2026-10-01 Add the bill of materials behind the USD 83 figure
    Thirteen line items in hardware/BOM.csv, summing to exactly 83.00, which is
    the figure the abstract and Section 2.1 quote. Until now the number had a
    five-category breakdown behind it and nothing itemised, so a reader could not
    check it or rebuild the device.
    Also corrects the part names in hardware/README.md. The Fritzing library names
    its ADS1115, BME680 and CCS811 symbols after Adafruit, and the earlier README
    repeated that, but the units built with were generic AliExpress equivalents at
    roughly a third of the price. That difference is most of why the sensing array
    comes to $15.80, so naming it matters: priced as Adafruit parts the total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
    [BOM.csv]
2026-10-01 Compute the Section 4.6 statistics in the deposited TVOC script
    Section 4.6 quotes a within-class coefficient of variation, a class-mean
    range, and a TVOC-against-eCO2 correlation decomposed between and within
    classes. None of those were computed by any deposited script, so three of the
    section's load-bearing numbers had no code behind them.
    analysis/tvoc_checks.py now emits all of them, and every figure reproduces
    what the manuscript states:
    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
2026-10-02 Compute paired per-seed differences in the leave-one-sensor-out script
    Section 3.3 and Supplementary Table S5 quote the cost of dropping a channel as
    a paired per-seed difference, 0.89 +/- 0.63 points for MQ-9 on three channels
    and -0.13 +/- 0.16 on four. The deposited script computed each subset's
    accuracy independently and reported the difference of the seed means, whose
    standard deviation is a different and larger quantity.
    analysis/loso.py now evaluates the full and reduced models at the same seeds
    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
2026-10-02 Update README with wiring and cost caveats
    Clarified wiring and cost details in the README.
2026-10-03 Add preparation-level leave-one-sensor-out, and Zenodo record metadata
    Reviewer 1 asked that generalization claims rest on the preparation-level holdout rather than shuffled cross-validation. The leave-one-sensor-out ablation only ran under shuffled CV, which mixes tria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
    analysis/loso.py now repeats the ablation under the batch A/B holdout across ten forest seeds. Removing MQ-9 costs -0.89 +/- 2.61 points on three channels and -1.22 +/- 1.92 on four, with the reduced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
2026-10-25 README: add device photo from tharunnambi.com
2026-10-25 Update filament description in README
